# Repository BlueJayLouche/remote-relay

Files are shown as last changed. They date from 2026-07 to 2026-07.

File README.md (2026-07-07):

# remote-relay

Fire a relay on cue from a lighting or show-control desk over WiFi. An **ESP32-C3**
receives **sACN (E1.31)** or **OSC** and switches a relay on/off — built to trigger
a theatre **aroma diffuser's** air pump, but it's just a network-controlled relay
and works for anything a desk should switch.

Push a fader up / fire a cue → relay closes. Pull it down, or lose the network →
relay opens. Failsafes force it **off** on WiFi loss, on a 2.5 s sACN stream gap,
and after an optional Max-ON timeout.

## Quick start

```bash
pio run -e c3 -t upload      # compile + flash over USB-C
pio device monitor           # watch logs (115200)
```

1. Join the setup WiFi **`AromaDiffuser-setup`** (password `aroma1234`), browse to
   **`http://192.168.4.1/`**, and set your show network + protocol/addresses.
2. Once on your network, it's at **`http://aroma.local/`** — live status, a **Test
   puff** button, and a **Config** page to change protocol, universe/channel,
   hostname, etc. without re-flashing.

## Details

- **[IMPLEMENTATION.md](IMPLEMENTATION.md)** — wiring, bill of materials, safety,
  configuration, bench-testing, and behaviour reference.
- **[ESP32_Relay/](ESP32_Relay/README.md)** — the custom carrier PCB (KiCad).

Target: ESP32-C3 Super Mini · PlatformIO env `c3` · arduino-esp32 v3 (pioarduino).

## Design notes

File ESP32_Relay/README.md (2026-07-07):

# ESP32_Relay — AromaDiffuser carrier board

A basic 2-layer carrier PCB for the [AromaDiffuser](../IMPLEMENTATION.md) controller:
**12 V in → buck → ESP32-C3 Super Mini → transistor → relay → pump out.**

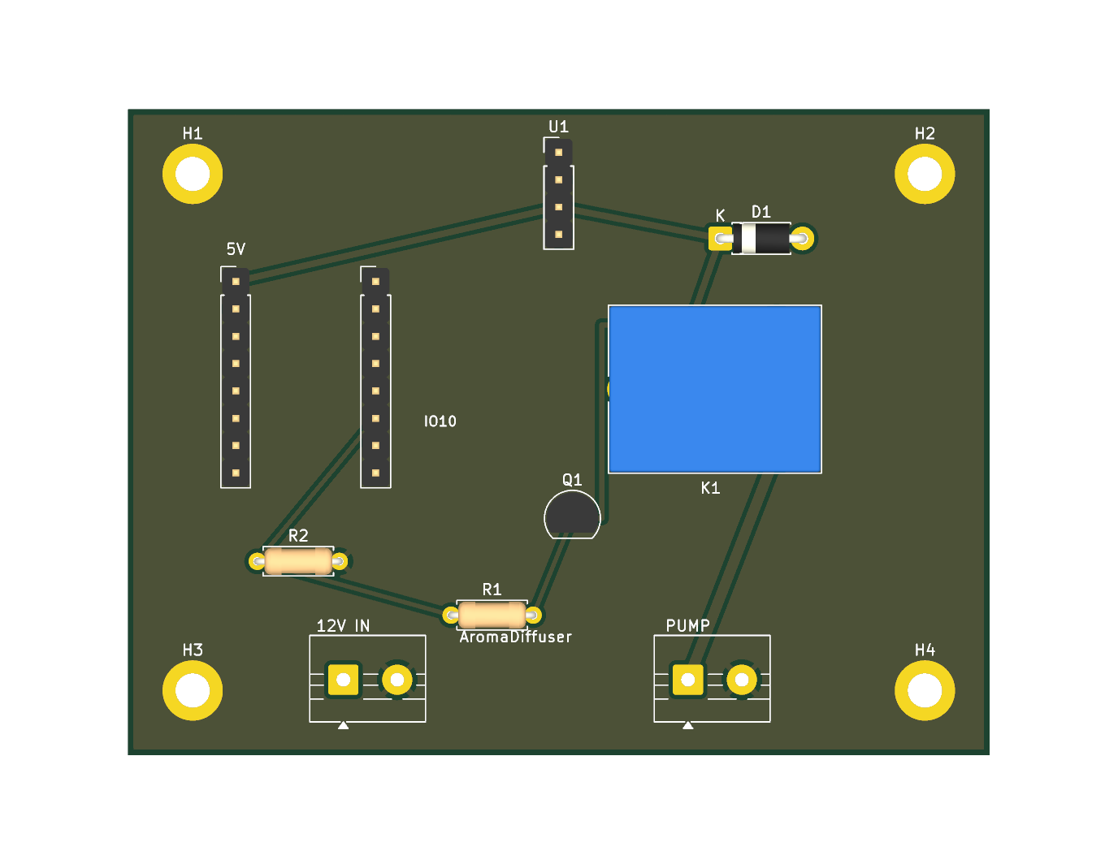
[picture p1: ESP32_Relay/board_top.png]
board top


~80 × 60 mm, 2-layer, **fully routed** with a GND pour. The relay is a dry SPDT
contact, so the switched side works for an **AC or DC** pump (subject to the mains
caveat below).

## How it was generated

Three scripts, run in order with KiCad's bundled Python. KiCad has no schematic
Python API, so each `.kicad_*` is written directly; the schematic and PCB are kept
consistent by sharing the same net names.

```bash
KPY=/Applications/KiCad/KiCad.app/Contents/Frameworks/Python.framework/Versions/Current/bin/python3
$KPY gen_board.py    # footprints, nets, GND pour, outline, mounting holes
$KPY gen_sch.py      # matching schematic (symbols + net labels)
$KPY gen_routes.py   # route the 6 non-GND nets
```

Verified with `kicad-cli`: schematic **ERC clean**, PCB **DRC clean (0 violations,
0 unrouted)**, and the schematic netlist matches the PCB. See `schematic.pdf`.

> The PCB carries its own netlist (no sheet-to-board link). If you edit the
> schematic and want to push changes, re-run `gen_routes.py` rather than KiCad's
> "Update PCB from schematic".

## ⚠️ Before you fabricate — verify these

It's DRC/ERC-clean, but still **bench-verify** the part-specific assumptions:

1. **C3 header pitch.** `A1`/`A2` are 2× 1×8 headers, rows **13 mm** apart. "Super
   Mini" clones vary — measure yours and adjust the `A1`/`A2` X positions in
   `gen_board.py` if needed before fab.
2. **Relay pinout.** Wired to the KiCad **SANYOU SRD** map (derived from the symbol):
   pin 1 = COM, pin 3 = NO, pins 2 & 5 = coil, pin 4 = NC (unused). Confirm your
   relay matches (SRD-05VDC-SL-C does).
3. **Transistor pinout.** Laid out for **PN2222A** in TO-92, pads 1-2-3 = **E-B-C**.
   A BC547 is C-B-E — different. Match the part to the footprint or you'll cook it.
4. **Mains pump = STOP.** This board's spacing (2.54 mm / 5 mm) is for a **low-voltage
   DC pump only**. If your pump is **AC mains**, do *not* run mains on this board —
   keep the mains switching on a separately mains-rated relay module off-board, or
   redesign for proper creepage/clearance + fusing + enclosure. (We still haven't
   measured the pump — do that first; see IMPLEMENTATION.md.)
5. **Buck.** `U1` is an **MP1584 module** on a 1×4 header — set its trimmer to **5.0 V
   before** connecting the C3.

## Netlist (matches `schematic.pdf` and the PCB)

| Net | Connections |
|-----|---|
| **+12V** | J1.1 (12V IN), U1.1 (buck VIN+), K1.1 (relay COM) |
| **+5V** | U1.3 (buck VOUT+), A1.1 (C3 5V), K1.2 (coil+), D1.1 (diode K) |
| **GND** | J1.2, U1.2, U1.4, A1.2 (C3 GND), Q1.1 (emitter), R2.2, J2.2, H1–H4, pour |
| **CTRL_IO10** | A2.6 (C3 GPIO10), R1.1, R2.1 |
| **Q_BASE** | R1.2, Q1.2 (base) |
| **COIL_DRV** | Q1.3 (collector), K1.5 (coil−), D1.2 (diode A) |
| **PUMP** | K1.3 (relay NO), J2.1 |

`R2` (10 k, GPIO10→GND) holds the transistor off during boot/reset → **pump off at
power-up**. `D1` is the coil flyback (band/cathode to +5 V).

## BOM

| Ref | Part | Notes |
|-----|---|---|
| A1, A2 | 2× 1×8 socket header, 2.54 mm | seat the ESP32-C3 Super Mini |
| U1 | MP1584 buck module + 1×4 header | 12 V → **5.0 V** |
| K1 | SPDT relay, 5 V coil | SRD-05VDC-SL-C (or pin-compatible) |
| Q1 | NPN BJT, TO-92 | PN2222A (E-B-C) |
| D1 | diode, DO-41 | 1N4007 |
| R1 | resistor | 1 kΩ (base) |
| R2 | resistor | 10 kΩ (pulldown) |
| J1, J2 | 2-pin screw terminal, 5 mm | J1 = 12V IN, J2 = PUMP |
| H1–H4 | M3 mounting holes | grounded |

## Fab

Export gerbers:

```bash
/Applications/KiCad/KiCad.app/Contents/MacOS/kicad-cli pcb export gerbers --output gerbers/ ESP32_Relay.kicad_pcb
/Applications/KiCad/KiCad.app/Contents/MacOS/kicad-cli pcb export drill   --output gerbers/ ESP32_Relay.kicad_pcb
```

…or just upload `ESP32_Relay.kicad_pcb` directly to JLCPCB/PCBWay.

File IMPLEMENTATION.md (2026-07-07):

# AromaDiffuser — Network → Pump Trigger

Fire a theatre aroma diffuser on cue from a lighting/show-control desk over the
network. An **ESP32-C3** receives either **sACN (E1.31)** or **OSC** and switches
the diffuser's **air pump** on/off. Push a fader up / fire a cue → scent releases.
Pull it down (or lose the network) → scent stops.

WiFi is set from a **captive-portal config page** — no re-flashing per venue — and
an **always-on status page** shows live state, has a **Test puff** button for tech
rehearsals, and lets you **edit all show settings live** (protocol, universe/channel,
hostname, …) without reopening the portal.

---

## How it works

The diffuser's original controller (the AXTEK MCU board, with its phone app and
built-in scheduler) is a sealed, mask-ROM chip — not reflashable, not worth
reverse-engineering. So we **don't touch its brain**. The scent is released by a
**12 V air pump**; we just drive that pump ourselves and bin the rest.

```
Desk / QLab ──sACN or OSC──▶ [show network] ──▶ ESP32-C3
                                                     │ GPIO10
   value ≥ threshold = pump ON                       ▼
   value < threshold = pump OFF                     relay ──▶ air pump (12 V)
   lost network / failsafe = pump OFF                        from diffuser PSU
```

Reused from the original unit: its **12 V power supply** (the wall brick) and the
**pump** itself. Everything else (the original PCB, app, RTC scheduler) is unused.

**sACN vs OSC** — they fail differently, and the firmware handles each correctly:

| | sACN (E1.31) | OSC |
|---|---|---|
| Style | continuous DMX stream | fire-and-forget events (e.g. QLab) |
| Trigger | one universe + channel, value ≥ threshold | one address, arg ≥ 0.5 / non-zero (bare message = ON) |
| Stream-loss failsafe | **yes** — no packets for 2.5 s = OFF | n/a (events don't stream); pump holds last command |
| Stuck-on safety | covered by failsafe | the **Max-ON watchdog** + **lost-WiFi = OFF** |

Both protocols also fail to OFF the instant **WiFi drops** (lost network = lost
control).

---

## ⚠️ Safety — read first

1. **Scent failsafes are built in.** Losing WiFi forces the pump OFF (both
   protocols). On **sACN**, a 2.5 s gap in the stream also forces OFF. On **OSC**
   (events, no stream), set **Max ON seconds** in the config page to a sensible
   cap (e.g. 30) so a missed "off" cue or a crashed QLab can't leave scent pumping
   forever. A dead show-network can never flood the house.
2. **Boot-safe pump.** Use a **HIGH-level-trigger** relay module and fit a **10 kΩ
   resistor from GPIO10 to GND**. That guarantees the pump stays OFF during boot,
   reset, and any firmware crash. (A low-level-trigger module would fire the pump
   on every reset — don't use one here.)
3. **Mains.** If your pump turns out to be **AC mains** (see "Confirm the pump"
   below), all pump-side wiring must be done by someone competent to work on
   mains, in an enclosure, fused, with proper isolation. The relay handles AC or
   DC; *you* handle it safely.
4. **Scent in a room lingers.** Test dosing in the actual venue with the HVAC
   running. Short bursts go a long way. Check for audience allergies/asthma per
   your venue's policy.

---

## Bill of materials

| Qty | Part | Notes |
|----|---|---|
| 1 | ESP32-C3 Super Mini | You have these. WiFi-only is fine — both sACN and OSC run over WiFi. |
| 1 | **HIGH-level-trigger** opto-isolated relay module (5 V coil) | Switches the pump. Handles AC *or* DC, so we don't need to know which yet. |
| 1 | 10 kΩ resistor | GPIO10 → GND, keeps pump OFF at boot. |
| 1 | 12 V→5 V buck (MP1584 or similar) | Powers the C3 + relay coil off the diffuser's 12 V. *Or* just power the C3 from any USB brick. |
| — | The diffuser's 12 V PSU + its pump | Salvaged from the original unit. |
| — | Hookup wire, an enclosure | Stage kit lives hard — box it. |

Silent / solid-state alternative: swap the relay for a logic-level N-MOSFET
(e.g. IRLZ44N) + flyback diode — **DC pump only**. Ask and I'll give that variant.

**Custom PCB:** the wiring above uses off-the-shelf modules. There's also an
all-on-board carrier PCB (ESP32-C3 + transistor + relay + buck on one board) in
[`ESP32_Relay/`](ESP32_Relay/README.md) — a generated KiCad project, DRC-clean,
ready to route and fab. Read its "verify before fab" notes first (esp. the mains
caveat).

---

## Wiring

ESP32-C3 Super Mini:

| C3 pin | Connects to | Why |
|---|---|-----|
| `GPIO10` | relay `IN` (and 10 kΩ to GND) | pump control; pulldown = boot-safe OFF |
| `5V` | buck 5 V out | board power |
| `GND`  | common ground (buck, relay, PSU) | **all grounds must be common** |
| `GPIO8` | onboard LED (built-in) | status indicator, no wiring needed |

Pump power circuit (relay switches the pump's low side):

```
12V PSU (+) ─────────────▶ pump (+)
pump (−) ───▶ relay COM
relay NO ───▶ 12V PSU (−)         ← relay closes = pump runs
relay VCC ◀── 5V      relay GND ──▶ common GND      relay IN ◀── GPIO10
```

> The C3's GPIO is 3.3 V; opto-isolated relay modules trigger fine from 3.3 V
> while their coil runs off the 5 V `VCC`. Keep **one common ground** between the
> C3, the buck and the relay or the relay won't switch reliably.

---

## Build & flash (PlatformIO)

```bash
# from this folder
pio run -e c3 -t upload      # compile + flash over USB-C
pio device monitor           # watch logs (115200)
```

If the C3 won't auto-enter its bootloader: **hold BOOT (GPIO9), tap RST, release
BOOT**, then run upload again.

On the serial monitor you should see:

```
AromaDiffuser  proto=sACN
Config AP: "AromaDiffuser-setup"  pass: aroma1234  (browse to 192.168.4.1)
WiFi up: 192.168.x.x
sACN: universe=1 channel=1 threshold=128
Web UI: http://aroma.local
[pump] ON
[pump] off
```

---

## Configure for your show (web page)

First-time setup uses a **captive-portal config page** (WiFiManager) — nothing to
re-flash. The portal opens automatically on **first boot** (no WiFi saved), or
**on demand**: hold the **BOOT** button while powering up. After it's on your
network, you can also change everything except WiFi live at `http://aroma.local/`
(see "Changing settings later" below).

1. From a phone/laptop, join the WiFi network **`AromaDiffuser-setup`** (password
   **`aroma1234`**).
2. The config page pops up (or browse to **`http://192.168.4.1/`** — type the full
   `http://`, or the browser may search instead of connecting). Set:
   - **WiFi** — pick your show network + password
   - **Protocol** — `sacn` or `osc`
   - **[sACN] universe** (1–63999), **channel** (1–512), **threshold** (1–255, default 128)
   - **[OSC] address** (default `/aroma`) and **UDP port** (default 8000)
   - **Max ON seconds** (0 = unlimited) — stuck-on safety; **set this for OSC**
3. Save. The unit stores it in flash, reboots, and connects. It remembers across
   power cycles — next show day it just powers up and runs.

Fill in only the fields for your chosen protocol; the others are ignored.

**Changing settings later — two ways:**
- **Live (normal case):** just browse to **`http://aroma.local/`** on the show
  network and edit protocol / universe / channel / threshold / OSC / Max-ON /
  hostname in the **Config** section — no portal, no BOOT button. Saving stores to
  flash and reboots (~2 s) to apply. See "Live status & config page" below.
- **WiFi portal:** to change the **WiFi network** (or if it's unreachable), hold
  **BOOT** at power-up to reopen the captive portal (times out after 3 min and
  carries on with saved settings).

**Driving it from the desk:**
- **sACN** — patch a channel at the universe/slot you set; send **≥ threshold**
  to release, below it to stop.
- **OSC** — send to the device IP, your UDP port, address `/aroma` (or what you
  set). `/aroma 1` (or `1.0`, or a bare `/aroma`) releases; `/aroma 0` stops.
  In **QLab**, two Network cues — one `/aroma 1` on the scent cue, one `/aroma 0`
  to stop.

WiFi reliability for show day: put this on a **dedicated router/AP**, not house
WiFi. sACN over congested WiFi drops packets, and a 2.5 s gap trips the failsafe
OFF mid-cue. A quiet dedicated 2.4 GHz AP for the show network is plenty.

> The setup AP is **WPA2**, password **`aroma1234`** (an open softAP fails to
> associate with macOS/iOS on the ESP32-C3). Change it in `configure()` if you want.

---

## Live status & config page

Once running, the unit serves an always-on page at **`http://aroma.local/`** (or
its IP) — leave it open on a phone at the tech table:

- Live **pump state** (big indicator), protocol, IP, WiFi signal, and the active
  config.
- A **Test puff** button fires the pump for **2 s** regardless of whether a desk
  is connected — so you can prove the scent works during focus, before any cue
  exists.
- A **Config** section to edit protocol, universe/channel/threshold, OSC
  address/port, Max-ON, and **hostname** live. Saving writes to flash and reboots
  (~2 s) to apply — the page shows "saved — rebooting…", then reconnect.

The status view polls a tiny `/status.json`; it runs alongside sACN/OSC without
disturbing cue timing. (`aroma.local` needs mDNS/Bonjour — built into macOS/iOS;
on Windows use the IP shown on the serial monitor.)

> **Hostname:** if you change it in the Config section, the `.local` address
> changes too — the unit is then at **`http://<newname>.local/`** (the old
> `aroma.local` stops resolving). Note it down, or find it by IP.

---

## Bench test before you trust it on stage

1. Flash, open the serial monitor, confirm `WiFi up:` and an IP.
2. Open **`http://aroma.local`** and hit **Test puff** — the relay clicks and the
   pump runs for 2 s. Quickest proof the hardware works, no desk needed.
3. Send a real cue:
   - **sACN** — from **sACNView** / **QLC+** / your desk, set the universe + channel
     to `255`. Serial prints `[pump] ON`, LED solid, pump runs; drop to `0` → off.
   - **OSC** — from QLab or a tool like **Protokol/OSC sender**, send `/aroma 1`
     then `/aroma 0`.
4. **Failsafe test (do this!):** with the pump ON, pull the network / kill the
   sender. On sACN it goes off within 2.5 s; on OSC, drop WiFi and it goes off
   immediately. Verify before you trust it in front of an audience.

---

## Behaviour reference

| Situation | Pump | Onboard LED |
|---|---|---|
| Config portal open (first boot / BOOT held) | OFF | — |
| WiFi connecting / lost | OFF (forced) | fast blink |
| Value below threshold / OSC "off" | OFF | off |
| Value at/above threshold / OSC "on" | **ON** | solid |
| No sACN for 2.5 s | OFF (forced) | off |
| Web "Test puff" pressed | **ON** for 2 s | solid |
| Max-ON seconds exceeded | OFF (forced) | off |
| Boot / reset / crash | OFF (pulldown) | — |

---

## Still to confirm — measure the pump

We sized everything around a 12 V DC pump (the board has a 12 V rail). Before
final wiring, trigger the original diffuser once via its app and meter the
**AC/PUMP** connector while it runs:

- **Voltage + AC or DC?** Confirms PSU + relay rating. If it's AC mains, see Safety #3.
- **Current draw** (or the pump's printed rating) — confirms a standard relay
  copes (it almost certainly does).

Send me those two numbers and I'll confirm the relay/PSU choice.

---

## Upgrade paths (only if you actually need them)

- **Timed bursts** — auto-puff of fixed length per trigger so a held fader doesn't
  over-saturate (start a timer on the rising edge, auto-off after N ms). Max-ON is
  a blunt version of this today.
- **Variable intensity** — PWM the pump from the channel/arg value via a MOSFET.
- **Manual ON/OFF + all-stop on the web page** — the page has a Test puff today;
  add latching control if an operator wants to drive it by hand.
- **Wired Ethernet** — swap the C3 for a WT32-ETH01; same logic, real Ethernet,
  no WiFi packet loss. Best if the desk network is wired.

Say which and I'll extend the sketch.

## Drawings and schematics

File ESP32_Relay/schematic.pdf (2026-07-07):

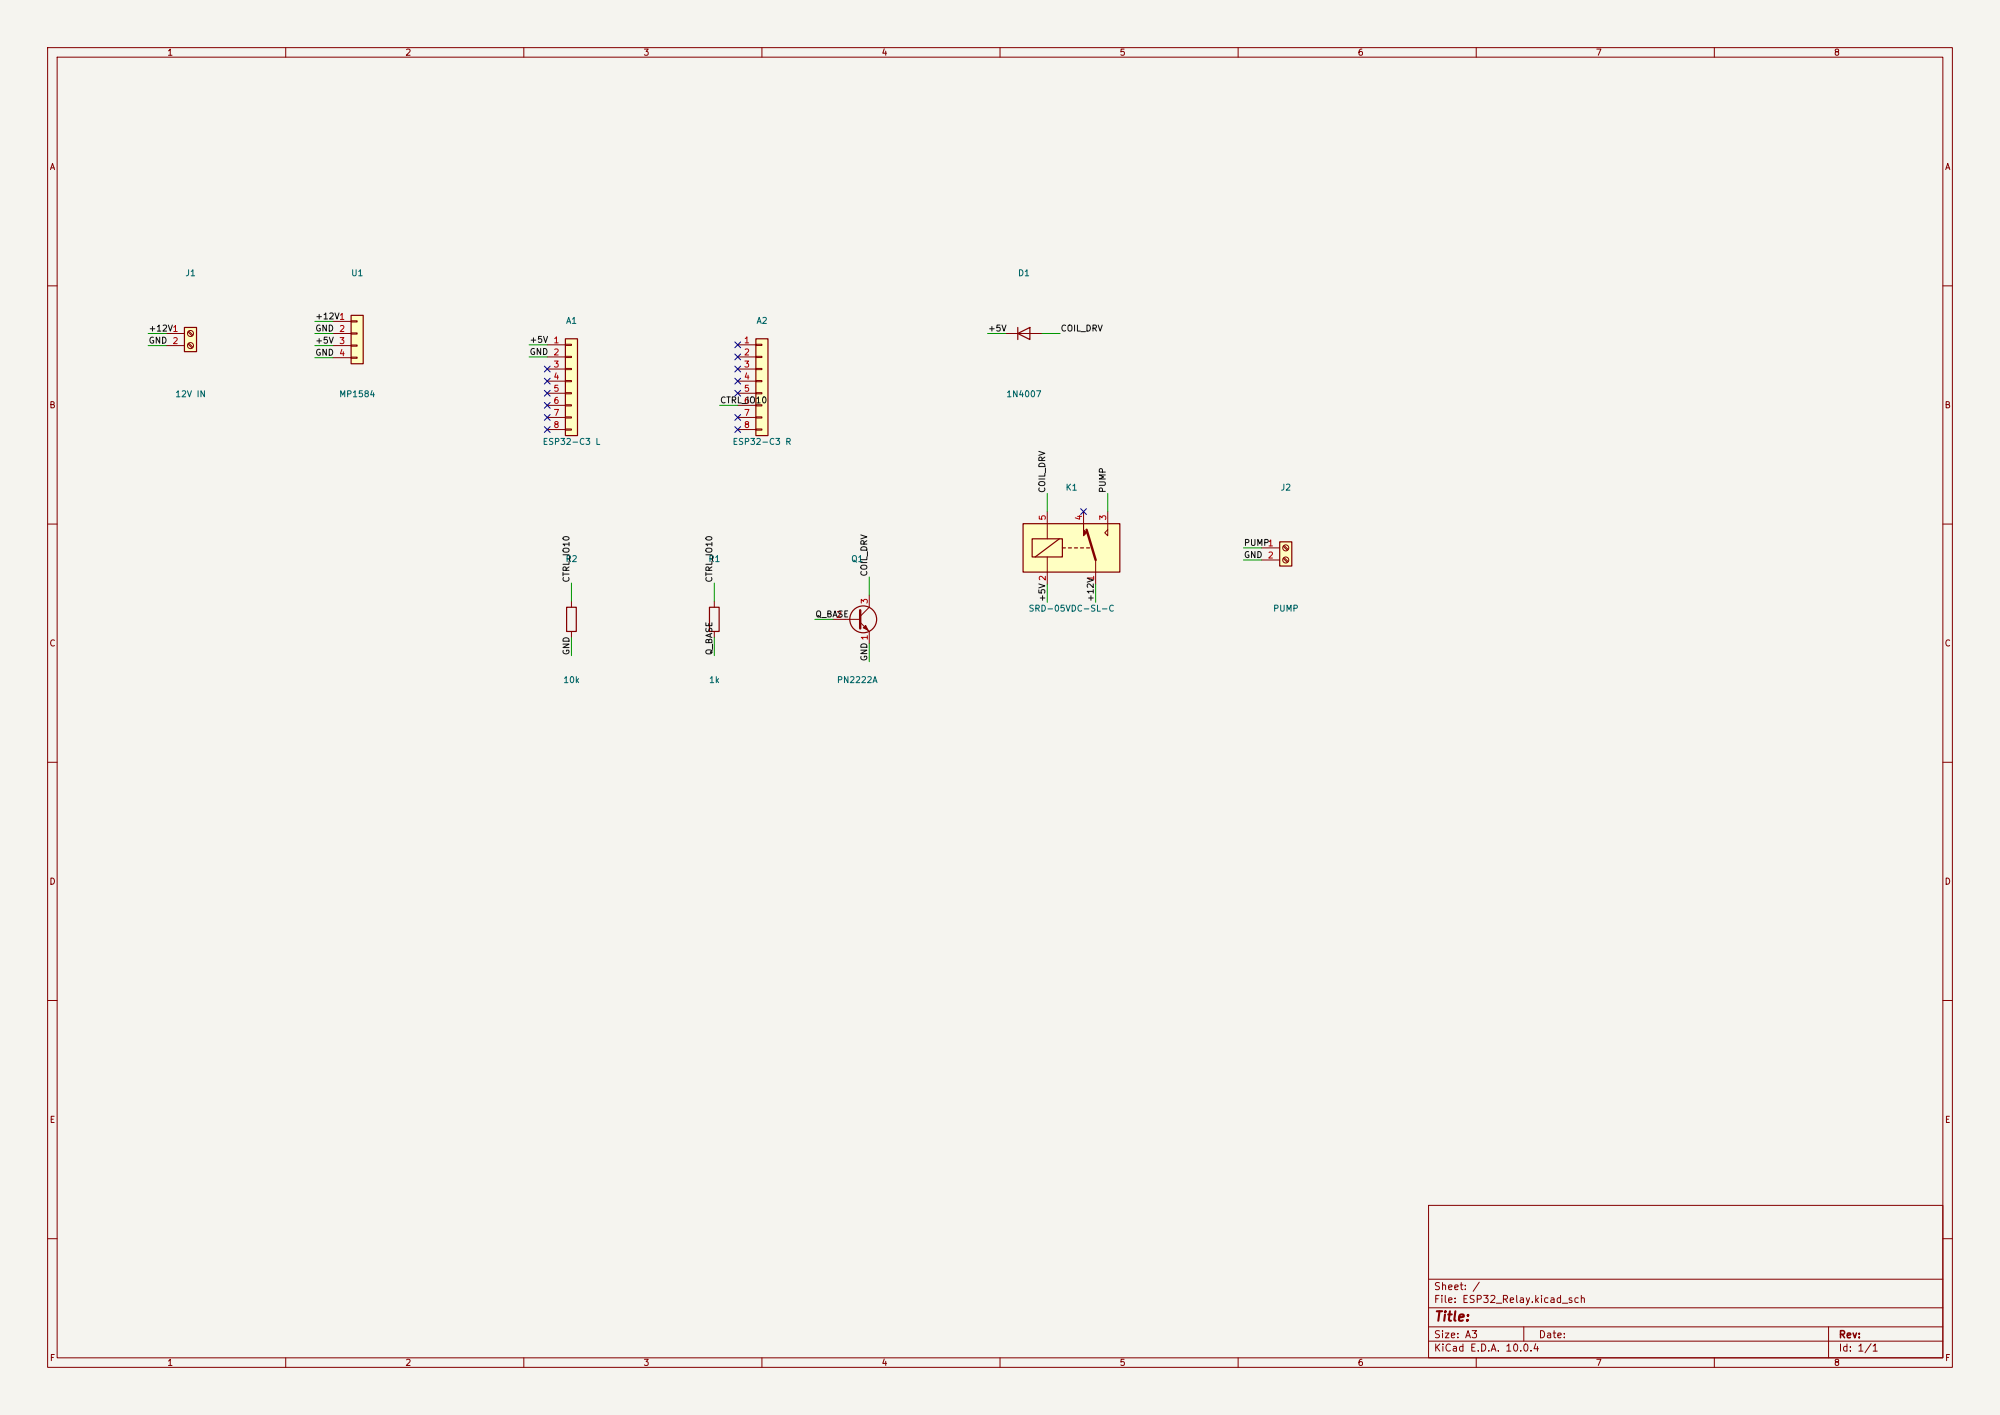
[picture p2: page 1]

Size: A3 | Rev: | F Date:
KiCad E.D.A. 10.0.4 | Id: 1/1

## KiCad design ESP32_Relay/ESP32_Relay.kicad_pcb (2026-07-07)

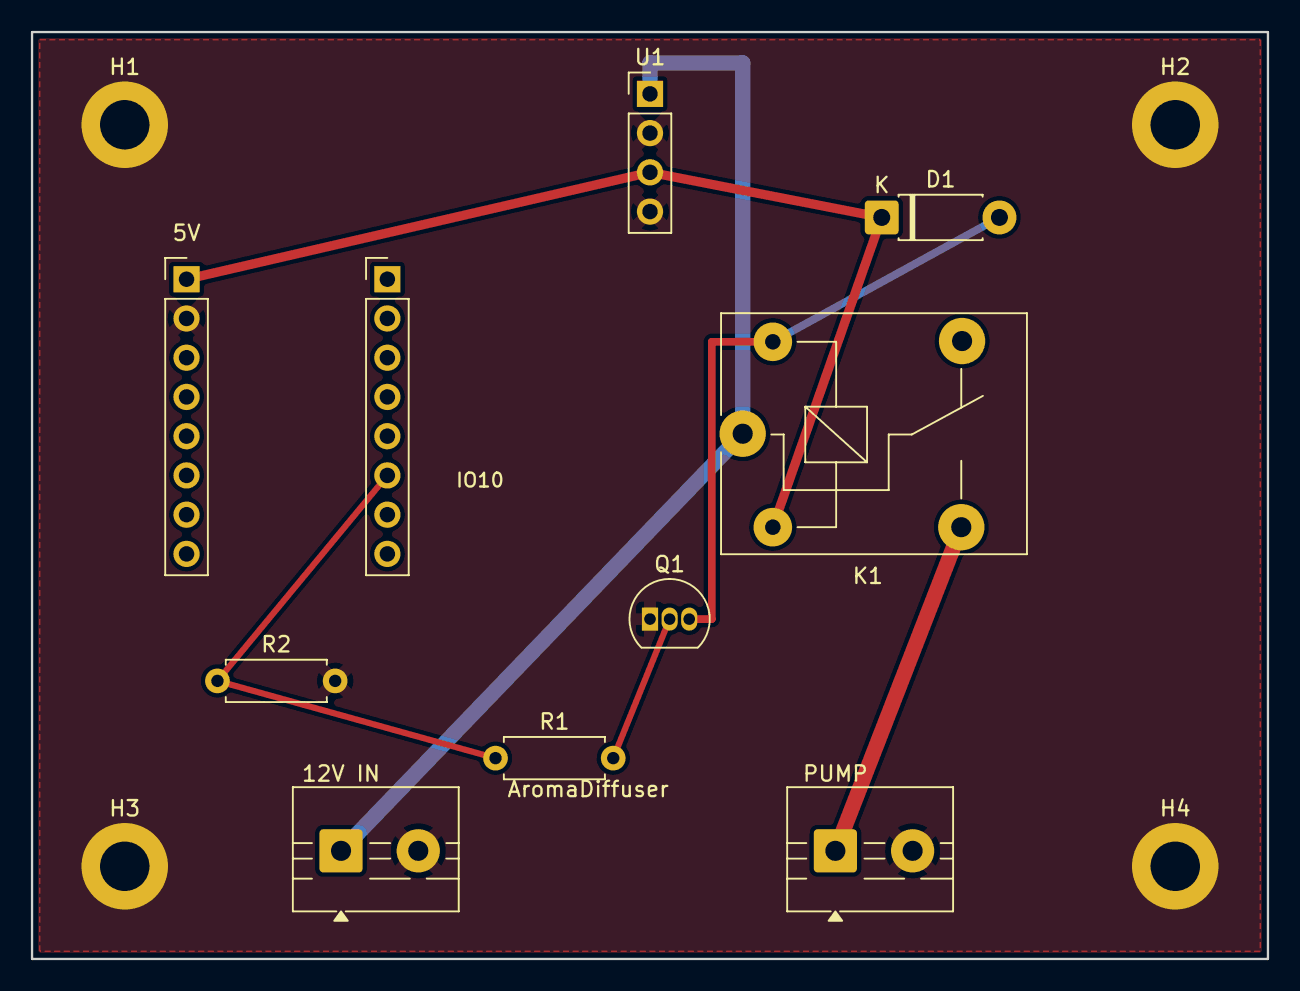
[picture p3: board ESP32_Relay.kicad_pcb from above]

Board: 2 copper layers, 80.0 x 60.0 mm, 14 parts (0 on the bottom side), 7 nets.

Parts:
A1: C3 L:5V,GND,3V3,IO4,IO3,IO2,IO1,IO0; PinHeader_1x08_P2.54mm_Vertical
A2: C3 R:IO5,IO6,IO7,IO8,IO9,IO10,RX,TX; PinHeader_1x08_P2.54mm_Vertical
D1: 1N4007 (band=K -> +5V); D_DO-41_SOD81_P7.62mm_Horizontal
H1, H2, H3, H4: MountingHole_3.2mm_M3_DIN965_Pad
J1: 12V IN; TerminalBlock_MaiXu_MX126-5.0-02P_1x02_P5.00mm
J2: PUMP; TerminalBlock_MaiXu_MX126-5.0-02P_1x02_P5.00mm
K1: 5V relay SRD-05VDC-SL-C; Relay_SPDT_SANYOU_SRD_Series_Form_C
Q1: PN2222A E-B-C; TO-92_Inline
R1: 1k base; R_Axial_DIN0207_L6.3mm_D2.5mm_P7.62mm_Horizontal
R2: 10k pulldown; R_Axial_DIN0207_L6.3mm_D2.5mm_P7.62mm_Horizontal
U1: MP1584 12V->5V: VIN+,VIN-,VOUT+,VOUT-; PinHeader_1x04_P2.54mm_Vertical

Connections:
+5V: A1.1, D1.1, K1.2, U1.3
+12V: J1.1, K1.1, U1.1
COIL_DRV: D1.2, K1.5, Q1.3
CTRL_IO10: A2.6, R1.1, R2.1
GND: A1.2, H1.1, H2.1, H3.1, H4.1, J1.2, J2.2, Q1.1, R2.2, U1.2, U1.4
PUMP: J2.1, K1.3
Q_BASE: Q1.2, R1.2

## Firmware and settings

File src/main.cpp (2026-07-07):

/*
 * AromaDiffuser — sACN (E1.31) OR OSC -> pump trigger for a theatre aroma diffuser.
 *
 * An ESP32-C3 joins the show network, receives cues over the network and switches
 * the diffuser's air pump on/off through a relay. The original diffuser controller
 * (the AXTEK MCU board) is bypassed entirely — we reuse only its 12 V PSU and pump.
 *
 * Two control protocols, picked on the config page:
 *
 *   sACN (E1.31)   continuous DMX stream. Watch one universe/channel; pump fires
 *                  when the channel value >= threshold. "No packets for 2.5 s = OFF"
 *                  failsafe (the stream stopping means something is wrong).
 *
 *   OSC            event messages (e.g. from QLab). One configurable address; the
 *                  argument decides on/off ( >=0.5 / non-zero = ON, bare msg = ON ).
 *                  Events are fire-and-forget, so there is NO stream-timeout
 *                  failsafe — the pump holds its last command. Stuck-on is caught
 *                  by the Max-ON watchdog and by "lost WiFi = OFF".
 *
 * Safety, both protocols: losing WiFi forces the pump OFF, and an optional Max-ON
 * watchdog force-stops scent after N seconds.
 *
 * WiFi is set from a captive-portal web page (WiFiManager) at first boot; hold
 * BOOT (GPIO9) at power-up to reopen it. Protocol/universe/channel/hostname etc.
 * are also editable live at http://<hostname>.local/ (saves to NVS + reboots).
 *
 * Target: ESP32-C3 Super Mini (WiFi only).   PlatformIO env: c3
 */

#include <WiFiManager.h>          // WiFi + the config-portal web server
#include <Preferences.h>
#include <WiFiUdp.h>
#include <OSCMessage.h>           // CNMAT/OSC
#include <ESPAsyncWebServer.h>    // always-on status page
#include <ESPmDNS.h>
#include <string.h>

// ─── Hardware pins ───────────────────────────────────────────────────────────
static const uint8_t  PUMP_PIN    = 10;     // -> relay IN. 10k pulldown to GND = boot-safe OFF
static const uint8_t  LED_PIN     = 8;      // onboard status LED
static const uint8_t  BTN_PIN    = 9;      // BOOT button — hold at power-up to open config
static const uint8_t  LED_ON      = HIGH;   // active-LOW Super Mini clone? set this to LOW
static const bool     RELAY_ON    = HIGH;   // HIGH-level-trigger relay: HIGH energises = pump on
static const uint32_t FAILSAFE_MS = 2500;   // sACN network-data-loss window (E1.31)

// ─── Runtime config (loaded from NVS, set via the portal) ────────────────────
bool     useOsc    = false;        // false = sACN, true = OSC
uint16_t universe  = 1;            // [sACN] universe patched on the desk
uint16_t channel   = 1;            // [sACN] DMX slot 1..512 that fires the scent
uint8_t  threshold = 128;          // [sACN] value at/above which the pump fires
String   oscAddr   = "/aroma";     // [OSC] address to listen on
uint16_t oscPort   = 8000;         // [OSC] UDP port to listen on
uint16_t maxOn     = 0;            // Max ON seconds, 0 = unlimited (stuck-on watchdog)
String   hostname  = "aroma";      // mDNS name -> http://<hostname>.local

static const uint16_t SACN_PORT = 5568;   // E1.31

Preferences    prefs;
WiFiManager    wm;
WiFiUDP        udp;                // shared transport (sACN multicast OR OSC — one at a time)
AsyncWebServer server(80);        // always-on status page
uint8_t        pkt[638];          // one E1.31 packet (126-byte header + up to 512 slots)
uint32_t       lastPacket = 0;
uint32_t       pumpSince  = 0;
uint32_t       puffUntil  = 0;     // web Test button: force pump on until this millis()
uint32_t       rebootAt   = 0;     // deferred restart after a config save (0 = none)
bool           pumpOn     = false;

inline void led(bool on) { digitalWrite(LED_PIN, on ? LED_ON : !LED_ON); }

void setPump(bool on) {
  if (on == pumpOn) return;        // edge-only: log + write on change
  pumpOn = on;
  if (on) pumpSince = millis();
  digitalWrite(PUMP_PIN, on ? RELAY_ON : !RELAY_ON);
  Serial.printf("[pump] %s\n", on ? "ON" : "off");
}

// ─── Config persistence ──────────────────────────────────────────────────────
void loadCfg() {
  prefs.begin("aroma", true);
  useOsc    = prefs.getBool  ("osc", false);
  universe  = prefs.getUShort("uni", 1);
  channel   = prefs.getUShort("ch",  1);
  threshold = prefs.getUChar ("thr", 128);
  oscAddr   = prefs.getString("oaddr", "/aroma");
  oscPort   = prefs.getUShort("oport", 8000);
  maxOn     = prefs.getUShort("maxon", 0);
  hostname  = prefs.getString("host", "aroma");
  prefs.end();
}

void saveCfg() {
  prefs.begin("aroma", false);
  prefs.putBool  ("osc",   useOsc);
  prefs.putUShort("uni",   universe);
  prefs.putUShort("ch",    channel);
  prefs.putUChar ("thr",   threshold);
  prefs.putString("oaddr", oscAddr);
  prefs.putUShort("oport", oscPort);
  prefs.putUShort("maxon", maxOn);
  prefs.putString("host",  hostname);
  prefs.end();
}

// Open the WiFiManager portal (forced if BOOT was held), then persist whatever the
// form returned. Blocks while the portal is up. Reboots if no WiFi results.
void configure(bool force) {
  char su[7], sc[6], st[6], sp[7], sm[7];
  snprintf(su, sizeof su, "%u", universe);
  snprintf(sc, sizeof sc, "%u", channel);
  snprintf(st, sizeof st, "%u", threshold);
  snprintf(sp, sizeof sp, "%u", oscPort);
  snprintf(sm, sizeof sm, "%u", maxOn);
  WiFiManagerParameter p_proto("proto", "Protocol: sacn or osc", useOsc ? "osc" : "sacn", 5);
  WiFiManagerParameter p_uni  ("uni",   "[sACN] universe (1-63999)", su, 6);
  WiFiManagerParameter p_ch   ("ch",    "[sACN] channel (1-512)",    sc, 4);
  WiFiManagerParameter p_thr  ("thr",   "[sACN] threshold (1-255)",  st, 4);
  WiFiManagerParameter p_addr ("oaddr", "[OSC] address",  oscAddr.c_str(), 31);
  WiFiManagerParameter p_port ("oport", "[OSC] UDP port", sp, 6);
  WiFiManagerParameter p_max  ("maxon", "Max ON seconds (0 = unlimited)", sm, 5);
  for (auto p : {&p_proto, &p_uni, &p_ch, &p_thr, &p_addr, &p_port, &p_max})
    wm.addParameter(p);
  wm.setConfigPortalTimeout(180);  // give up the portal after 3 min, carry on
  // C3 softAP in modem-sleep drops association frames -> macOS "association failed".
  // Kill power-save the moment the portal AP comes up.
  wm.setAPCallback([](WiFiManager*){ WiFi.setSleep(WIFI_PS_NONE); });

  Serial.println("Config AP: \"AromaDiffuser-setup\"  pass: aroma1234  (browse to 192.168.4.1)");
  bool ok = force ? wm.startConfigPortal("AromaDiffuser-setup", "aroma1234")
                  : wm.autoConnect("AromaDiffuser-setup", "aroma1234");

  // getValue() == the submitted form value, or our defaults if the portal never
  // opened — so this is a safe no-op re-save when WiFi connected straight away.
  useOsc    = (strcasecmp(p_proto.getValue(), "osc") == 0);
  universe  = constrain(atoi(p_uni.getValue()),  1, 63999);
  channel   = constrain(atoi(p_ch.getValue()),   1, 512);
  threshold = constrain(atoi(p_thr.getValue()),  1, 255);
  oscAddr   = p_addr.getValue();
  if (oscAddr.isEmpty() || oscAddr[0] != '/') oscAddr = "/aroma";
  oscPort   = constrain(atoi(p_port.getValue()), 1, 65535);
  maxOn     = constrain(atoi(p_max.getValue()),  0, 65535);
  saveCfg();

  if (!ok) { Serial.println("No WiFi — rebooting"); ESP.restart(); }
}

// ─── OSC receive ─────────────────────────────────────────────────────────────
void onOsc(OSCMessage &m) {
  bool on;
  if      (m.size() == 0)  on = true;                       // bare message = ON
  else if (m.isFloat(0))   on = m.getFloat(0) >= 0.5f;
  else if (m.isInt(0))     on = m.getInt(0) != 0;
  else                     on = true;
  setPump(on);
}

void pollOsc() {
  int size = udp.parsePacket();
  if (size <= 0) return;
  OSCMessage msg;
  while (size--) msg.fill(udp.read());
  if (!msg.hasError()) msg.dispatch(oscAddr.c_str(), onOsc);
}

// ─── sACN / E1.31 receive ────────────────────────────────────────────────────
// We only need one slot from one universe, so we parse the packet directly rather
// than pull in a library. (The usual ESPAsyncE131 lib uses Xtensa asm and will not
// build on the RISC-V C3.) sACN is multicast to 239.255.<uni-hi>.<uni-lo>:5568.
void sacnBegin(uint16_t uni) {
  udp.beginMulticast(IPAddress(239, 255, (uni >> 8) & 0xFF, uni & 0xFF), SACN_PORT);
}

void pollSacn() {
  int len = udp.parsePacket();
  if (len < 126) return;                                  // shorter than an E1.31 header
  int n = udp.read(pkt, sizeof pkt);
  if (n < 126) return;
  if (memcmp(pkt + 4, "ASC-E1.17", 9) != 0) return;       // ACN packet identifier
  uint16_t pktUni = (pkt[113] << 8) | pkt[114];
  if (pktUni != universe) return;                         // not our universe
  if (pkt[125] != 0x00) return;                           // not a 0-start-code DMX frame
  int idx = 125 + channel;                                // slot N lives at byte 125+N
  if (idx >= n) return;                                   // packet doesn't reach our slot
  lastPacket = millis();
  setPump(pkt[idx] >= threshold);
}

// ─── Always-on status page ───────────────────────────────────────────────────
static const char PAGE[] = R"HTML(<!doctype html><html><head><meta charset=utf-8>
<meta name=viewport content="width=device-width,initial-scale=1"><title>AromaDiffuser</title>
<style>body{font-family:system-ui,sans-serif;background:#111;color:#eee;text-align:center;margin:0;padding:1.5rem}
#dot{font-size:4rem;line-height:1}.on{color:#2dd4bf}.off{color:#444}
table{margin:1rem auto;border-collapse:collapse}td{padding:.2rem .8rem;text-align:left}
button{font-size:1.3rem;padding:1rem 2rem;margin-top:1rem;border:0;border-radius:.6rem;background:#2dd4bf;color:#012}
button:active{transform:scale(.97)}
form{max-width:340px;margin:1.5rem auto 0;text-align:left}
label{display:block;margin:.6rem 0 .1rem;font-size:.9rem;color:#aaa}
input,select{width:100%;padding:.5rem;box-sizing:border-box;background:#222;color:#eee;border:1px solid #444;border-radius:.4rem;font-size:1rem}
hr{border:0;border-top:1px solid #333;margin:1.5rem 0}</style></head><body>
<h1>AromaDiffuser</h1><div id=dot class=off>&#9679;</div><div id=state>&mdash;</div>
<table id=info></table><button onclick="fetch('/test')">Test puff (2s)</button>
<hr><h2>Config</h2>
<form id=cfg onsubmit="return save(event)">
<label>Hostname (.local)</label><input name=host maxlength=31>
<label>Protocol</label><select name=proto><option value=sacn>sACN (E1.31)</option><option value=osc>OSC</option></select>
<label>[sACN] Universe (1-63999)</label><input name=universe type=number min=1 max=63999>
<label>[sACN] Channel (1-512)</label><input name=channel type=number min=1 max=512>
<label>[sACN] Threshold (1-255)</label><input name=threshold type=number min=1 max=255>
<label>[OSC] Address</label><input name=addr maxlength=31>
<label>[OSC] UDP port</label><input name=port type=number min=1 max=65535>
<label>Max ON seconds (0 = unlimited)</label><input name=maxon type=number min=0 max=65535>
<button>Save &amp; reboot</button></form>
<script>async function tick(){try{
const s=await(await fetch('/status.json')).json(),on=s.pump==1;
const d=document.getElementById('dot');d.className=on?'on':'off';
document.getElementById('state').textContent=on?'SCENT ON':'idle';
let r=[['Protocol',s.proto],['IP',s.ip],['Signal',s.rssi+' dBm']];
if(s.proto=='osc')r.push(['OSC address',s.addr],['OSC port',s.port]);
else r.push(['Universe',s.universe],['Channel',s.channel],['Threshold',s.threshold]);
r.push(['Max ON',s.maxon?s.maxon+' s':'unlimited']);
document.getElementById('info').innerHTML=r.map(x=>`<tr><td>${x[0]}</td><td><b>${x[1]}</b></td></tr>`).join('');
}catch(e){document.getElementById('state').textContent='disconnected';}}
async function fill(){const s=await(await fetch('/status.json')).json(),f=document.cfg;
for(const k of['host','proto','universe','channel','threshold','addr','port','maxon'])f[k].value=s[k];}
async function save(e){e.preventDefault();
await fetch('/save',{method:'POST',body:new FormData(document.cfg)});
document.getElementById('state').textContent='saved — rebooting…';return false;}
fill();setInterval(tick,1000);tick();</script></body></html>)HTML";

void handleStatus(AsyncWebServerRequest *req) {
  // All fields always present so the config form can prefill regardless of proto.
  String j = "{";
  j += "\"proto\":\"" + String(useOsc ? "osc" : "sacn") + "\",";
  j += "\"pump\":"  + String(pumpOn ? 1 : 0) + ",";
  j += "\"ip\":\""  + WiFi.localIP().toString() + "\",";
  j += "\"rssi\":"  + String(WiFi.RSSI()) + ",";
  j += "\"host\":\"" + hostname + "\",";
  j += "\"universe\":" + String(universe) + ",\"channel\":" + String(channel) +
       ",\"threshold\":" + String(threshold) + ",";
  j += "\"addr\":\"" + oscAddr + "\",\"port\":" + String(oscPort) + ",";
  j += "\"maxon\":" + String(maxOn) + "}";
  req->send(200, "application/json", j);
}

// POST /save: persist the config form, then reboot to apply (re-inits listeners + mDNS).
void handleSave(AsyncWebServerRequest *r) {
  auto arg = [&](const char *k, const String &d) -> String {
    return r->hasParam(k, true) ? r->getParam(k, true)->value() : d;
  };
  useOsc    = arg("proto", "sacn") == "osc";
  universe  = constrain(arg("universe", "1").toInt(),  1, 63999);
  channel   = constrain(arg("channel", "1").toInt(),   1, 512);
  threshold = constrain(arg("threshold", "128").toInt(), 1, 255);
  oscAddr   = arg("addr", "/aroma");
  if (oscAddr.isEmpty() || oscAddr[0] != '/') oscAddr = "/aroma";
  oscPort   = constrain(arg("port", "8000").toInt(), 1, 65535);
  maxOn     = constrain(arg("maxon", "0").toInt(),   0, 65535);
  hostname  = arg("host", "aroma");
  if (hostname.isEmpty()) hostname = "aroma";
  saveCfg();
  r->send(200, "text/plain", "saved, rebooting");
  rebootAt = millis() + 400;                        // let the response flush first
}

void startWeb() {
  MDNS.begin(hostname.c_str());
  server.on("/", HTTP_GET, [](AsyncWebServerRequest *r) { r->send(200, "text/html", PAGE); });
  server.on("/status.json", HTTP_GET, handleStatus);
  server.on("/save", HTTP_POST, handleSave);
  server.on("/test", HTTP_GET, [](AsyncWebServerRequest *r) {
    puffUntil = millis() + 2000;                  // 2 s test puff
    r->send(200, "text/plain", "ok");
  });
  server.begin();
  MDNS.addService("http", "tcp", 80);
  Serial.printf("Web UI: http://%s.local\n", hostname.c_str());
}

void setup() {
  pinMode(PUMP_PIN, OUTPUT);
  digitalWrite(PUMP_PIN, !RELAY_ON);   // OFF before anything else
  pinMode(LED_PIN, OUTPUT);
  led(false);
  pinMode(BTN_PIN, INPUT_PULLUP);

  Serial.begin(115200);
  delay(200);
  loadCfg();
  Serial.printf("\nAromaDiffuser  proto=%s\n", useOsc ? "OSC" : "sACN");

  configure(digitalRead(BTN_PIN) == LOW);   // BOOT held = open config portal
  Serial.printf("WiFi up: %s\n", WiFi.localIP().toString().c_str());

  if (useOsc) {
    udp.begin(oscPort);
    Serial.printf("OSC: listening %s on UDP %u\n", oscAddr.c_str(), oscPort);
  } else {
    sacnBegin(universe);
    Serial.printf("sACN: universe=%u channel=%u threshold=%u\n", universe, channel, threshold);
    lastPacket = millis();
  }

  startWeb();
}

void loop() {
  if (rebootAt && millis() >= rebootAt) ESP.restart();   // deferred restart after /save

  if (WiFi.status() != WL_CONNECTED) {        // lost network = lost control = scent OFF
    setPump(false);
    led((millis() / 150) & 1);
    return;
  }

  if (millis() < puffUntil) {                 // web "Test" button overrides the protocol
    setPump(true);
    led(true);
    return;
  }

  if (useOsc) {
    pollOsc();                                // events hold last state (no stream timeout)
  } else {
    pollSacn();                               // updates lastPacket + pump on each frame
    if (millis() - lastPacket > FAILSAFE_MS) setPump(false);   // stream stopped -> scent off
  }

  if (pumpOn && maxOn && millis() - pumpSince >= (uint32_t)maxOn * 1000) {
    Serial.println("[pump] max-on watchdog");
    setPump(false);                           // stuck-on safety (both protocols)
  }

  led(pumpOn);
}

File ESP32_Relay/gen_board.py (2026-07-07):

#!/usr/bin/env python3
"""
Generate ESP32_Relay.kicad_pcb — a basic carrier board for the AromaDiffuser:
  12V IN -> MP1584 buck -> 5V -> ESP32-C3 Super Mini + relay coil
  GPIO10 -> 1k -> NPN base -> relay coil (flyback diode) -> SPDT relay
  relay COM = 12V, NO -> PUMP terminal ; 10k pulldown keeps the relay off at boot.

Run with KiCad's bundled Python (has pcbnew):
  /Applications/KiCad/KiCad.app/Contents/Frameworks/Python.framework/Versions/Current/bin/python3 gen_board.py

This writes the .kicad_pcb directly (pcbnew has no schematic API). The board
carries its own netlist — do NOT run "Update PCB from schematic" or it clears it.
ponytail: parts placed + netted + GND pour + outline; routing left to KiCad's
router (only ~6 nets). Verify the C3 header pitch and relay pinout before fab.
"""
import os, pcbnew
from pcbnew import VECTOR2I, FromMM

HERE = os.path.dirname(os.path.abspath(__file__))
FPBASE = "/Applications/KiCad/KiCad.app/Contents/SharedSupport/footprints"

# (lib, footprint)
HDR8  = ("Connector_PinHeader_2.54mm", "PinHeader_1x08_P2.54mm_Vertical")
HDR4  = ("Connector_PinHeader_2.54mm", "PinHeader_1x04_P2.54mm_Vertical")
TERM2 = ("TerminalBlock", "TerminalBlock_MaiXu_MX126-5.0-02P_1x02_P5.00mm")
RELAY = ("Relay_THT", "Relay_SPDT_SANYOU_SRD_Series_Form_C")
TO92  = ("Package_TO_SOT_THT", "TO-92_Inline")
RAX   = ("Resistor_THT", "R_Axial_DIN0207_L6.3mm_D2.5mm_P7.62mm_Horizontal")
DIODE = ("Diode_THT", "D_DO-41_SOD81_P7.62mm_Horizontal")
HOLE  = ("MountingHole", "MountingHole_3.2mm_M3_DIN965_Pad")  # annular pad -> tie to GND

board = pcbnew.NewBoard(os.path.join(HERE, "ESP32_Relay.kicad_pcb"))

def place(ref, spec, x, y, rot=0, value=""):
    lib, name = spec
    fp = pcbnew.FootprintLoad(os.path.join(FPBASE, lib + ".pretty"), name)
    fp.SetReference(ref)
    if value:
        fp.SetValue(value)
    board.Add(fp)
    fp.SetPosition(VECTOR2I(FromMM(x), FromMM(y)))
    if rot:
        fp.SetOrientationDegrees(rot)
    return fp

# ── Nets ─────────────────────────────────────────────────────────────────────
def net(name):
    n = pcbnew.NETINFO_ITEM(board, name)
    board.Add(n)
    return n

GND, V12, V5 = net("GND"), net("+12V"), net("+5V")
CTRL, BASE, COILDRV, PUMP = net("CTRL_IO10"), net("Q_BASE"), net("COIL_DRV"), net("PUMP")

# ── Place parts (mm) ─────────────────────────────────────────────────────────
A1 = place("A1", HDR8, 110, 116, value="C3 L:5V,GND,3V3,IO4,IO3,IO2,IO1,IO0")
A2 = place("A2", HDR8, 123, 116, value="C3 R:IO5,IO6,IO7,IO8,IO9,IO10,RX,TX")
U1 = place("U1", HDR4, 140, 104, value="MP1584 12V->5V: VIN+,VIN-,VOUT+,VOUT-")
R2 = place("R2", RAX, 112, 142, value="10k pulldown")
R1 = place("R1", RAX, 130, 147, value="1k base")
Q1 = place("Q1", TO92, 140, 138, value="PN2222A E-B-C")
D1 = place("D1", DIODE, 155, 112, value="1N4007 (band=K -> +5V)")
K1 = place("K1", RELAY, 146, 126, value="5V relay SRD-05VDC-SL-C")
J1 = place("J1", TERM2, 120, 153, value="12V IN")
J2 = place("J2", TERM2, 152, 153, value="PUMP")
for ref, (hx, hy) in {"H1": (106, 106), "H2": (174, 106),
                      "H3": (106, 154), "H4": (174, 154)}.items():
    h = place(ref, HOLE, hx, hy)
    hp = h.FindPadByNumber("1")
    if hp:
        hp.SetNet(GND)            # grounded mounting holes -> no hole-in-pour clearance hit

# Hide the descriptive value text on silk (keeps refs; notes live in properties).
for fp in board.GetFootprints():
    fp.Value().SetVisible(False)
# Hide refs where a clearer silk label replaces them (C3 headers + terminals).
for fp in (A1, A2, J1, J2):
    fp.Reference().SetVisible(False)

# Silk labels so the board is self-documenting (terminals + C3 orientation).
def silk(text, x, y, size=1.0):
    t = pcbnew.PCB_TEXT(board)
    t.SetText(text)
    t.SetLayer(pcbnew.F_SilkS)
    t.SetPosition(VECTOR2I(FromMM(x), FromMM(y)))
    t.SetTextSize(VECTOR2I(FromMM(size), FromMM(size)))
    t.SetTextThickness(FromMM(0.15))
    board.Add(t)

silk("AromaDiffuser", 136, 149)
silk("12V IN", 120, 148)
silk("PUMP", 152, 148)
silk("5V", 110, 113)          # A1 pin 1
silk("IO10", 129, 129, 0.9)   # A2 pin 6
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
